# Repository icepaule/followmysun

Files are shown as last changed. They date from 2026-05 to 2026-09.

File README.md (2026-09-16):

# FollowMySun

> Astronomisch geführte Sonnenstand-Nachführung für ein einzelnes PV-Modul auf einem Gartenhaus-Dach. Basierend auf ESP8266 (ESP12F-Relay-X4), MPU-6050-Beschleunigungssensor und einem 12 V Linear-Aktuator – mit MQTT-Anbindung an Home Assistant inkl. Sturm-Notfallmodus.

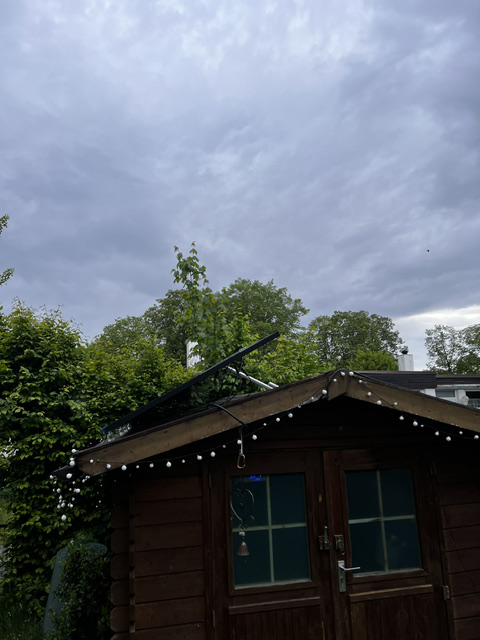
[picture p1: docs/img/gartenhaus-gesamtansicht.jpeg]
Gesamtansicht – Gartenhaus mit aufgestelltem PV-Panel


---

## Was macht das Ding?

Ein einzelnes PV-Modul auf dem 32°-Dach eines Gartenhauses wird durch einen 12 V Linear-Aktuator zwischen 32° (flach auf dem Dach) und ca. 59° (Aktuator voll ausgefahren) verstellt. Ein MicroPython-Programm auf einem ESP12F berechnet aus Datum, Uhrzeit und Standort den optimalen Panel-Winkel zur Sonne, misst per MPU-6050-Beschleunigungssensor den aktuellen Ist-Winkel und steuert über zwei Relais die Polarität am Aktuator.

Alle Werte werden per MQTT an einen Broker geschickt – damit baut sich in Home Assistant ein Live-Dashboard. Über ein Command-Topic (`cmnd/solar/EMERGENCY = on`) lässt sich das Panel bei Unwetterwarnung sofort flach auf das Dach fahren.

## Features

- **Astronomische Sonnenstand-Berechnung** für jeden Tag des Jahres und jede Tageszeit
- **MPU-6050-Regelung** mit asymmetrischer Hysterese (Start ab 2° Abweichung, Stopp ab 0,5° + Overshoot-Erkennung)
- **MQTT** mit JSON-Vollpayload + einzelnen Topics für Home-Assistant-Sensoren
- **Notfallmodus** über MQTT (`cmnd/solar/EMERGENCY`) – Panel sofort in Schutzposition
- **Hardware-Watchdog** (~3 s) gegen ESP-Hänger
- **WebREPL** zur Wartung übers WLAN (kein USB nötig nach Einbau)
- **Mini-Webserver** zur manuellen Steuerung im Browser
- **Kalibrierungs-Layer** mit Offset/Sign – Sensor-Achsenrichtung muss nicht physisch perfekt sitzen

## Hardware

| Bauteil | Funktion |
|---|---|
| **ESP12F-Relay-X4 v1.2** | ESP8266 + 4 Relais, davon 2 genutzt | 
| **MPU-6050 (GY-521)** | Beschleunigungssensor zur Winkelmessung |
| **Linear-Aktuator 12 V** mit Endschaltern | Verstellt das Panel-Gestell |
| **DC/DC-Stepdown-Wandler** | 12 V → 5 V Versorgung des ESP |
| **CAT5-Kabel ~2,5 m** | Verlängert I2C-Bus vom Controller zum Sensor am Panel |

### Steuerung im Gartenhaus

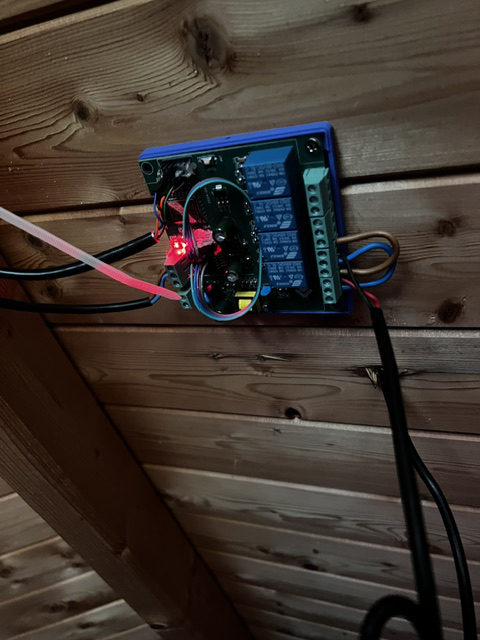
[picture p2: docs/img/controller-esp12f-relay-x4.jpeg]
ESP12F-Relay-X4 Controller im Gehäuse


Der Controller hängt geschützt unter der Dachschräge. Die zwei roten LEDs zeigen, welches Relais gerade aktiv ist.

### Stromversorgung

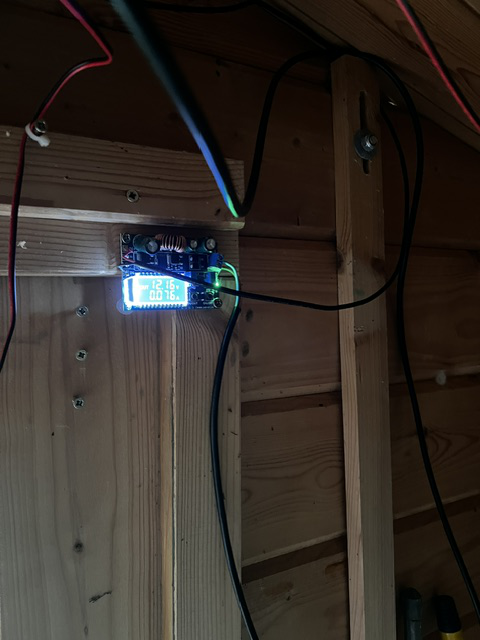
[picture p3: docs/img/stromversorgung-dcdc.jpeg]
DC/DC-Stepdown-Wandler 12V→5V


Ein einstellbarer Stepdown-Wandler erzeugt die 5 V für den ESP aus der 12 V Aktuator-Versorgung – ein Netzteil reicht für alles.

### MPU-Sensor am Panel

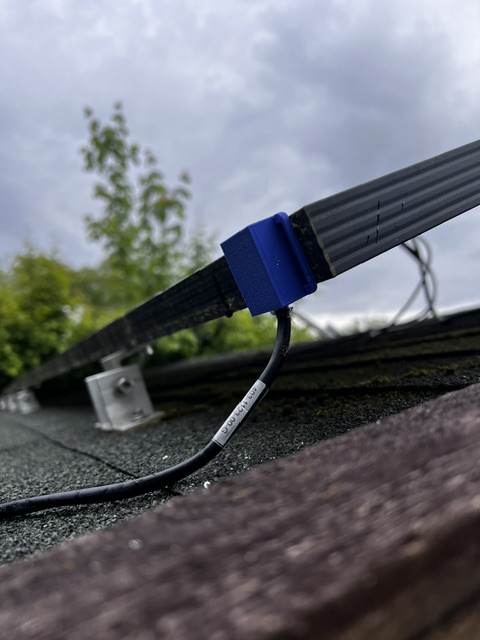
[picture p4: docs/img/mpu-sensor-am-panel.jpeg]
MPU-6050 am Panel-Rahmen


Der MPU-6050 sitzt in einem 3D-gedruckten Gehäuse direkt am PV-Rahmen und misst die Neigung gegen die Schwerkraft. Verkabelt mit CAT5 zum Controller.

## Schnellstart

1. **Hardware nach Pinbelegung verdrahten** (siehe [docs/hardware.md](docs/hardware.md))
2. **MicroPython auf ESP12F flashen** ([docs/installation.md](docs/installation.md))
3. **`src/env.example.py` → `env.py` kopieren** und Werte einfüllen (WLAN, MQTT, Sensor-Achsen)
4. **Code als `.mpy` kompilieren** (sonst MemoryError beim Parsen):
   ```bash
   python -m mpy_cross solar_main.py
   ```
5. **Dateien hochladen** (USB oder WebREPL): `boot.py`, `main.py`, `env.py`, `mpu6050.mpy`, `solar_main.mpy`
6. **Strom an** – fertig. Webseite unter `http://<esp-ip>/`, MQTT-Topics unter `tele/solar/...`

Detaillierte Anleitung: **[docs/installation.md](docs/installation.md)**

> **Migration auf ESP32 mit externer Antenne:** Wenn ihr das Setup an einem
> WLAN-schwachen Standort betreibt (z. B. Gartenhaus / Schuppen), gibt es eine
> ausführliche Umbau-Doku vom ESP12F-Relay-X4 auf den **Olimex ESP32-EVB-EA Rev.L**
> mit IPEX-Externantenne: **[docs/hardware-migration-esp32-evb.md](docs/hardware-migration-esp32-evb.md)** —
> inkl. Mermaid-Diagrammen für IST- und SOLL-Verkabelung sowie dem korrekten
> 12 V-Split über einen Mini-360-Buck (das neue Board ist strikt 5 V!).

### 3D-Druck-Gehäuse für den Olimex-Controller

Olimex ESP32-EVB-EA Rev.L Gehäuse v0.3

Für die Überkopfmontage des neuen Controllers **im Schuppen unter dem Dach** gibt es jetzt ein eigenes parametrisches Gehäuse in **v0.3**. Es bietet Zugang zu den sechs Aktuator-Schraubklemmen, Micro-USB, PWR1, UEXT/Dupont, externer WLAN-Antenne und RST1; der nicht benötigte CAN-Anschluss bleibt geschlossen.

- **[Gehäuse-Dokumentation](docs/housing-esp32-evb.md)** – Maße, Anschlussöffnungen, Explosionsansicht, Druckhinweise und Fit-Test
- **[OpenSCAD-Quelle + Build-Script](hardware/enclosure/olimex-esp32-evb-ea-v0.3/)** – erzeugt Base, Lid, Reset-Button, Fit-Test und ZIP reproduzierbar

## MQTT-Topics für Home Assistant

| Topic | Richtung | Beispiel | Beschreibung |
|---|---|---|---|
| `tele/solar/SENSOR` | ESP→ | JSON | Vollpayload mit allen Werten |
| `tele/solar/SENSOR/PanelAngle` | ESP→ | `35.4` | Aktueller Panel-Winkel (kalibriert) |
| `tele/solar/SENSOR/TargetAngle` | ESP→ | `42.1` | Soll-Winkel |
| `tele/solar/SENSOR/SunAngle` | ESP→ | `45.0` | Berechneter optimaler Winkel |
| `tele/solar/SENSOR/MotionText` | ESP→ | `Hoch` | `Stopp` / `Hoch` / `Runter` |
| `tele/solar/SENSOR/MinAngle` | ESP→ | `32.0` | Mechanisches Untermass |
| `tele/solar/SENSOR/MaxAngle` | ESP→ | `58.7` | Mechanisches Obermass |
| `tele/solar/SENSOR/Emergency` | ESP→ | `false` | Notfall-Status |
| `cmnd/solar/EMERGENCY` | →ESP | `on` / `off` | Notfall an/aus (retained!) |

Vollständig: **[docs/mqtt.md](docs/mqtt.md)** · NodeRED-Sturm-Automatik: **[docs/nodered-stormwatch.md](docs/nodered-stormwatch.md)**

## Notfall-Modus für Sturmwarnung

Aus Node-RED bei Unwetterwarnung:

```javascript
msg.topic = 'cmnd/solar/EMERGENCY';
msg.payload = 'on';
msg.retain = true;   // wichtig: ueberlebt ESP-Reboot
return msg;
```

Der ESP fährt das Panel sofort auf `MIN_ANGLE` (Dachneigung, flach) und ignoriert Auto-Modus + manuelle Web-Befehle. Bei `off` wechselt er zurück in den Astro-Modus.

## Repo-Struktur

```text
followmysun/
├── README.md
├── src/                       # Tracker-Firmware
├── docs/                      # Detail-Dokumentation
│   ├── hardware.md
│   ├── installation.md
│   ├── mqtt.md
│   ├── calibration.md
│   ├── tracker-debugging.md
│   ├── hardware-migration-esp32-evb.md
│   ├── housing-esp32-evb.md   # 3D-Druck-Gehäuse Olimex v0.3
│   └── img/
├── hardware/
│   └── enclosure/
│       └── olimex-esp32-evb-ea-v0.3/  # SCAD, Build, Rev-L-Koordinaten, QA
└── _config.yml
```

## Tech-Stack

- **MicroPython 1.28** auf ESP8266 (ESP12F)
- **mpy-cross** für Bytecode-Kompilierung (sonst RAM-Limit)
- **paho-mqtt / mosquitto** als Broker
- **MPU-6050** mit `atan2`-basierter Roll-Berechnung
- **SoftI2C @ 100 kHz** (wegen 2,5 m CAT5-Strecke)

Details siehe [docs/software.md](docs/software.md).

## Lessons Learned

Drei Sachen, die mich am meisten Zeit gekostet haben:

1. **`mqtt.ping()` darf nicht in jeder Loop-Iteration aufgerufen werden** – sonst stempelt der Broker dich als misbehaving und schmeißt dich mit `ECONNRESET` raus. Throttling auf 1×/30 s.
2. **ESP8266 WLAN braucht aktiven Outbound-Traffic**, sonst lernen Router/Switches die MAC nicht zuverlässig zurück – ein UDP-Keepalive pro Sekunde an die Gateway-IP löst's.
3. **`solar_main.py` ist mit 33 KB zu groß zum Parsen** auf dem ESP8266 (Heap ~35 KB). Lösung: vorher mit `mpy-cross` zu `.mpy` (10 KB) kompilieren.

## Lizenz

MIT – siehe [LICENSE](LICENSE).

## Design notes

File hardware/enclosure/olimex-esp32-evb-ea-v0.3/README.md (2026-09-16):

# Olimex ESP32-EVB-EA Rev. L – Schuppendach-Gehäuse v0.3

Parametrisches 3D-Druck-Gehäuse für den **Olimex ESP32-EVB-EA Rev. L** des FollowMySun-Controllers. Es ist für die Montage **innerhalb des Schuppens, über Kopf unter dem Dach** ausgelegt.

## v0.3

- Zugang zu **CON1 + CON2**: zwei 3-polige DG306-5.0-Schraubklemmen / insgesamt sechs Aktuator-Anschlüsse.
- Gemeinsame seitliche Kabeleinführung für die sechs Klemmen: **33,1 × 13,5 mm**.
- Zwei untere Schraubendreher-Servicefenster: je **13 × 14 mm**.
- **Micro-USB / USB-UART1**: **13 × 8,5 mm**.
- **WLAN**: Ø **10,0 mm** durchgehend.
- **PWR1**: **11 × 11 mm**.
- **UEXT/Dupont**: **16 × 7 mm**.
- **RST1** über separaten gedruckten Plunger.
- **Kein CAN-Ausschnitt**.

## Abmessungen

| Merkmal | Maß |
|---|---:|
| Gehäuse ohne Laschen | 94 × 92 × 31 mm |
| Wandstärke | 2,6 mm |
| PCB-Standoff | 4,0 mm |
| WLAN | Ø 10,0 mm |
| PWR1 | 11 × 11 mm |
| UEXT/Dupont | 16 × 7 mm |
| Micro-USB | 13 × 8,5 mm |
| CON1+CON2 Seitenöffnung | 33,1 × 13,5 mm |
| Servicefenster Klemmen | 2 × 13 × 14 mm |
| RST1 Wandbohrung | Ø 4,2 mm |
| Dach-Montagebohrungen | Ø 4,5 mm |

## Dateien

- `olimex_esp32_evb_ea_roof_housing_v0.3.scad` – komplettes parametrisches Modell.
- `build.sh` – rendert Base, Lid, RST-Button und Fit-Test als STL und erzeugt ein ZIP.
- `SOURCE_POSITIONS.md` – verwendete Rev.-L-Koordinaten.
- `MESH_QA.json` – Prüfergebnis der bereits erzeugten Referenz-STLs.

Die gerenderten Referenz-STLs sind wegen ihrer Größe nicht doppelt im Git-Tree abgelegt. Sie lassen sich mit `build.sh` aus der versionierten SCAD-Quelle reproduzieren.

## Bauen

Voraussetzungen: OpenSCAD CLI, `zip`, `sha256sum`.

```bash
cd hardware/enclosure/olimex-esp32-evb-ea-v0.3
chmod +x build.sh
./build.sh
```

Die Ergebnisse liegen danach unter `dist/`.

## Druck

Für den dauerhaften Einbau im Schuppen: **PETG oder ASA**. PLA eignet sich vor allem für den Fit-Test. Startwerte: 0,20 mm Layer, 4 Perimeter, 25–35 % Infill, 5 Top-/Bottom-Layer.

Vor dem großen Druck zuerst `fit_test_v0.3.stl` erzeugen und WLAN-, PWR-, Micro-USB- und Klemmenmaße am realen Aufbau prüfen.

Ausführliche Projektdokumentation: [`docs/housing-esp32-evb.md`](../../../docs/housing-esp32-evb.md).

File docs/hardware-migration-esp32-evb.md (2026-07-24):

---
title: Hardware-Migration ESP12F-Relay-X4 → Olimex ESP32-EVB-EA
---

# Hardware-Migration: ESP12F-Relay-X4 v1.2 → Olimex ESP32-EVB-EA Rev.L

Diese Doku beschreibt den Umbau des Solar-Tracker-Controllers vom ESP8266-basierten
**ESP12F-Relay-X4 v1.2** auf den ESP32-basierten **Olimex ESP32-EVB-EA Rev.L** mit
externer WLAN-Antenne. Ziel: mehr RAM, robusteres WLAN am schlechten Empfangsort
(Schuppen), OTA-Fähigkeit.

> → Alle vier Schaltbilder kompakt auf einer Seite: [Wiring-Übersicht ESP32-EVB](wiring-esp32-evb.html)

> **TL;DR** — Ihr könnt das alte Board 1:1 tauschen, müsst aber die **12 V-Zuleitung
> umkonzepieren**: das neue Board ist strikt 5 V. Nötig sind zusätzlich ein
> Mini-360 Step-Down und eine WAGO-T-Verzweigung.

## Warum tauschen

| Aspekt | ESP12F-Relay-X4 (alt) | Olimex ESP32-EVB-EA (neu) |
|---|---|---|
| MCU | ESP8266 @ 80/160 MHz | ESP32 dual-core @ 240 MHz |
| RAM | ~36 KB | 520 KB |
| Flash | 4 MB | 4 MB |
| WLAN-Antenne | PCB (auf ESP-12F) | externe IPEX + Stab-Antenne |
| Firmware-Form | `.mpy` (RAM-Druck) | `.py` direkt |
| OTA möglich | nein | ja |
| Crash-Profil | gelegentliche Heap-Crashes | nur noch Software-Bugs realistisch |

## Big Picture: alle Anschlüsse im Vergleich

| Aspekt | ALT – ESP12F-Relay-X4 v1.2 | NEU – Olimex ESP32-EVB-EA |
|---|---|---|
| Board-Stromversorgung | 12 V direkt an VIN-Klemme (Board hat eigenen Buck 12→5→3.3 V) | **Nur 5 V zulässig!** → Mini-360 Buck extern, dann DC-Jack 5.5×2.1 mm (Mitte +) |
| Aktuator-Versorgung | 12 V+ auf K1-COM, 12 V− auf K2-COM (vom Board-Vin abgezweigt) | 12 V+ auf REL1-COM, 12 V− auf REL2-COM (per WAGO parallel zur 5-V-Erzeugung) |
| Relais-Steuerung | GPIO16 (K1 = Runter), GPIO14 (K2 = Hoch) | GPIO32 (REL1 = Runter), GPIO33 (REL2 = Hoch) |
| I²C SDA | GPIO4 (D2) | GPIO13 = UEXT Pin 6 (Pull-up onboard) |
| I²C SCL | GPIO5 (D1) | GPIO16 = UEXT Pin 5 (Pull-up onboard) |
| MPU-6050 Versorgung | 3V3 + GND vom Board | 3V3 + GND aus UEXT Pin 1 / Pin 2 |
| Trenn-Bauteil dazwischen | keins nötig | **Mini-360 Step-Down** + **WAGO 221 T-Verzweigung** |

## Diagramm 1 — IST-Zustand ESP12F-Relay-X4

IST-Zustand ESP12F-Relay-X4

Der Boardregler zieht die 12 V selbst herunter, Relais K1/K2 schalten die
Aktuator-Adern in Polaritätsumkehr.

## Diagramm 2a — SOLL-Zustand Power-Pfad

SOLL Power-Pfad

Die 12 V-Zuleitung wird an einer WAGO 221 T-Verzweigung aufgeteilt:

- **Zweig A (Logik)**: 12 V → Mini-360 → getrimmt auf exakt 5.0 V → DC-Hohlstecker 5.5 × 2.1 mm (Mitte +) → Olimex DC-Jack → onboard TPS62A02 → 5 V / 3.3 V Rails.
- **Zweig B (Last)**: 12 V+ direkt an REL1-COM, 12 V− direkt an REL2-COM.

Gemeinsame Masse ist automatisch, weil beide Zweige aus derselben 12 V-Quelle kommen.

## Diagramm 2b — SOLL-Zustand Signal-/Last-Pfad

SOLL Signal- und Relais-Pfad

Olimex steuert die zwei Onboard-Relais REL1/REL2 (GPIO32/33), die Aktuator-Adern
hängen in Polarity-Reverse-Verdrahtung an NO/NC. MPU-6050 hängt komplett am
UEXT-Stecker (Pin 1/2/5/6).

## Diagramm 3 — Klemmen-Detail

Klemmen-Detail SOLL

Farbcode: rot = 12 V+, blau = 12 V−, gelb = 5 V, grün = Aktuator-Last.

## Stromversorgung Olimex — Warum kein 12 V direkt

Der onboard Buck-Regler des Olimex ESP32-EVB-EA ist ein **TPS62A02** mit
**Vin 2.5–5.5 V typ., abs. Max 6.5 V**. Alles darüber killt den Regler sofort.

Referenzen (offizielle Olimex-Doku):

- [ESP32-EVB Rev.L KiCad-Schaltplan (PDF)](https://github.com/OLIMEX/ESP32-EVB/blob/master/HARDWARE/REV-L/ESP32-EVB_Rev_L.pdf)
- [ESP32-EVB User Manual (PDF)](https://github.com/OLIMEX/ESP32-EVB/blob/master/DOCS/ESP32-EVB-user-manual.pdf)
- [TI TPS62A02 Datenblatt](https://www.ti.com/product/TPS62A02A)

### Was am Olimex **nicht** geht

- 12 V an DC-Jack — zerstört den TPS62A02.
- 12 V an EXT/UEXT Pin 1 — das ist der 5-V-Rail-Ausgang, kein Input.
- 12 V an die Schraubklemmen des Boards — die sind Relais-Kontakte (COM/NO/NC), keine Versorgung.
- PoE über RJ45 — der EVB hat keine PoE-PHY (das ist die separate `ESP32-POE`-Variante).

### Was geht

1. **DC-Jack 5.5 × 2.1 mm, Mitte +**, gespeist aus Mini-360-VOUT — cleanster Weg, Reverse-Polarity-Diode auf dem Board schützt.
2. **Micro-USB**, gespeist aus 5-V-USB-Netzteil oder Mini-360 + aufgetrenntes USB-Kabel — genauso sicher, mechanisch etwas fragiler.
3. **LiPo-Header** JST-PH 2 mm (`BAT1`) — nur wenn Batterie geplant.

### Auslegung Mini-360

| | |
|---|---|
| Last (Olimex + CH340 + MPU + 2 Relais-Spulen) | ~450 mA @ 5 V ≈ 2.25 W |
| Mini-360 max dauerhaft | 1.8 A → >4-fache Reserve |
| Wärme im geschlossenen Gehäuse | Handwarm; bei Bedenken: LM2596 mit Kühlkörper oder Traco TSR-1-2450 |

## Verkabelung Motor (Polarity-Reverse-Pattern)

Die zwei externen Relais des alten Aufbaus entfallen komplett — die Motor- und
Power-Adern gehen direkt in die Schraubklemmen der zwei Onboard-Relais des Olimex.

| Funktion | ALT – ESP12F-Relay-X4 | NEU – Olimex ESP32-EVB-EA |
|---|---|---|
| Motor „Runter" Steuerung | GPIO16 → K1-Spule (Board-intern) | GPIO32 (REL1) – onboard |
| Motor „Hoch" Steuerung | GPIO14 → K2-Spule (Board-intern) | GPIO33 (REL2) – onboard |
| Aktuator + | K1-NO | **REL1-NO + REL2-NC** |
| Aktuator − | K2-NO | **REL2-NO + REL1-NC** |
| 12 V + | K1-COM | **REL1-COM** |
| 12 V − | K2-COM | **REL2-COM** |

**Wenn Motorrichtung verkehrt**: entweder `PIN_RELAY1` / `PIN_RELAY2` in `env.py`
tauschen ODER Aktuator-Adern mechanisch in den Klemmen kreuzen — nicht beides.

## Verkabelung MPU-6050 an UEXT

Alle vier Adern gehen in den 10-pol IDC-UEXT-Stecker. Kein Löten nötig.

| MPU-6050 | ALT – ESP12F-Relay-X4 | NEU – Olimex UEXT (10-pol IDC) |
|---|---|---|
| VCC | 3V3 Stiftleiste | **UEXT Pin 1 (+3.3 V)** |
| GND | GND Stiftleiste | **UEXT Pin 2 (GND)** |
| SCL | GPIO5 (D1) | **UEXT Pin 5 → GPIO16** (Pull-up onboard) |
| SDA | GPIO4 (D2) | **UEXT Pin 6 → GPIO13** (Pull-up onboard) |
| AD0 | an GND (Adr. 0x68) | an GND (unverändert) |

UEXT-Pinout (Sicht von oben aufs Board, Pin 1 markiert):

```
   1 +3.3V    2 GND
   3 TXD      4 RXD
   5 SCL      6 SDA    ←── MPU-6050 hier
   7 MISO     8 MOSI
   9 SCK     10 SS
```

## Zusätzliche Bauteile

| Menge | Bauteil | Zweck | Bezug (Beispiel) |
|---|---|---|---|
| 1 | **Olimex ESP32-EVB-EA Rev.L** | neuer Controller | [olimex.com](https://www.olimex.com/Products/IoT/ESP32/ESP32-EVB/) ~20 € |
| 1 | **Mini-360** DC-DC-Buck (alternativ LM2596 mit Kühlkörper) | 12 V → 5.0 V für Olimex-Logik | Amazon 8er-Set ~8 € |
| 1 | **DC-Hohlstecker 5.5 × 2.1 mm, Mitte +**, zum Anlöten | Mini-360 → Olimex DC-Jack | Amazon / Reichelt |
| 2 | **WAGO 221** (3-Leiter) | T-Verzweigung 12 V+ und 12 V− | Baumarkt |
| 1 | **UEXT-IDC-Ribbon-Kabel 10-pol** (2×5, 2.54 mm, IDC-Buchse mit Codierung) | MPU-6050 an UEXT | Amazon (siehe unten) |
| — | 0.75 mm² / 1.5 mm² Kabel, Aderendhülsen | Verlängerung zu WAGO | Vorrat |
| — | Multimeter | Mini-360 auf 5.00 V trimmen | Vorrat |

## Werkbank-Checkliste

- [ ] Strom AUS am alten Solar-Tracker-Standort (12 V-Netzteil ausstecken)
- [ ] Antenne am Olimex: IPEX-Pigtail eingerastet + SMA-Stab aufgeschraubt (**VOR** Power-On!)
- [ ] Mini-360 auf der Werkbank auf **5.00 V trimmen** (Multimeter am Ausgang, ohne Olimex angeschlossen)
- [ ] WAGO 221 A (12 V+): 12 V+ vom Netzteil rein, 2 Leiter raus (zu Mini-360-VIN+ und zu REL1-COM)
- [ ] WAGO 221 B (12 V−): 12 V− vom Netzteil rein, 2 Leiter raus (zu Mini-360-VIN− und zu REL2-COM)
- [ ] DC-Hohlstecker: Mini-360-VOUT+ auf Innen-Pin, VOUT− auf Ring, in Olimex-DC-Jack
- [ ] Aktuator-Adern beim Erstboot noch ABGEKLEMMT lassen (GPIO32/33 wackeln kurz beim Boot)
- [ ] MPU-6050 4-adrig am UEXT-Stecker (Pin 1/2/5/6)
- [ ] 12 V-Netzteil einstecken → Olimex-LEDs an, Mini-360-LED an
- [ ] Nachmessen: DC-Jack-Eingang am Olimex zeigt 5.0 V (± 0.1)
- [ ] Aktuator-Adern in REL1/REL2-Klemmen gemäß Polarity-Reverse-Schema (Diagramm 3)
- [ ] Firmware-Deployment: `env.py`, `boot.py`, `main.py`, `mpu6050.py`, `solar_main.py` via `mpremote`
- [ ] Reset + MQTT-Test
- [ ] Motorrichtung OK? Falls nicht: PIN_RELAY1/2 in env.py tauschen ODER Aktuator-Adern kreuzen
- [ ] WLAN-RSSI prüfen — Erwartung ≥ −65 dBm mit externer Antenne

## Sicherheits-Reminder

- **Nie 12 V direkt** in irgendeinen Anschluss des Olimex.
- **Nie ohne Antenne** einschalten, wenn WLAN-Betrieb geplant ist (HF-Reflexion → Modul-Schaden).
- Mini-360-Poti **nie unter Last** verstellen (Overshoot möglich).
- Motor-Adern beim Erstboot **abklemmen** (Boot-Klick der Relais).
- **Keine 230 V** auf die Olimex-Relais — der Aufbau ist mechanisch nicht dafür isoliert.

## Firmware-Änderungen

Zur ESP8266→ESP32-Portierung sind minimale Code-Anpassungen nötig:

- **Firmware-Flash-Offset**: `0x1000` (statt `0x0` wie ESP8266).
- **PowerSave**: `sta.config(pm=sta.PM_NONE)` in `boot.py` (statt `esp.sleep_type(esp.SLEEP_NONE)`).
- **Compat-Shim** in `solar_main.py` für `esp.sleep_type()` (no-op auf ESP32).
- Kein `.mpy`-Compile mehr nötig; `solar_main.py` läuft direkt.
- **`init()`-Reihenfolge umgedreht**: WLAN zuerst → MQTT → MPU (optional) → HTTP → WDT. Damit bleibt der Remote-Zugang auch dann garantiert, wenn der MPU-6050 (noch) nicht am UEXT hängt. `sensor = None` sperrt automatisch jegliche Motorbewegung (Sicherheit), Web + MQTT laufen normal weiter und melden `MpuOk:false` inkl. Fehlercode.
- **Watchdog-Timeout: 30 s** (statt fest 3 s wie beim ESP8266) — genug Reserve, damit ein langsamer HTTP-Request keinen falschen Reset auslöst.

Siehe [software.md](software.md) für die generellen Firmware-Details.

## Eingebautes WebGUI + REST-API

Ausreichend RAM auf dem ESP32 (~80 kB frei im Betrieb) macht es möglich, den früher gestrichenen Mini-Webserver wieder mitlaufen zu lassen — nonblocking im Main-Loop, ohne Threads. Aufrufbar direkt unter `http://<esp-ip>/`:

- **Dashboard** (Auto-Refresh alle 4 s): Panel-Winkel, Ziel-Winkel, Sonnen-Winkel, Motorstatus, Emergency/Manual-Flags, WLAN-RSSI, Heap, Uptime, MPU-Status, ggf. LastError.
- **Motor manuell**: Buttons **Hoch / Runter / Auto**.
- **Notfall**: **EMERGENCY ON / OFF** (Panel sofort flach) + **Recalc** (Sonne neu berechnen).
- **Kalibrierung / Grenzen**: Feld für `SetAngle <grad>` (kalibriert den MPU-Offset live und persistiert ihn nach `/calib.json`) + Feld für `MIN_ANGLE` (0–70°).

Alle Aktionen laufen intern über dieselben Helper wie die MQTT-Commands (`action_set_emergency`, `action_manual`, `action_setangle`, `action_recalc`, `action_set_minangle`) — die REST-Endpoints sind ein reiner Alias-Pfad neben dem MQTT-Bus.

### REST-Endpoints

| Methode | Pfad | Payload (form-encoded) | Antwort |
|---|---|---|---|
| `GET` | `/` | — | HTML-Dashboard |
| `GET` | `/api/state` | — | JSON-Snapshot (identisches Schema wie MQTT-Topic `tele/solar/SENSOR`) |
| `POST` | `/api/manual` | `v=up\|down\|auto` | text/plain, z.B. `Manual: Up` |
| `POST` | `/api/emergency` | `v=on\|off` | `Emergency on` / `Emergency off` |
| `POST` | `/api/recalc` | — | `recalc: sun=X target=Y` |
| `POST` | `/api/setangle` | `v=<grad>` | `calib: offset=Z, panel=<grad>` |
| `POST` | `/api/minangle` | `v=<grad>` | `MIN_ANGLE=<grad>` |

Beispiel mit `curl`:

```bash
curl http://10.10.12.55/api/state | jq
curl -X POST -d "v=on"  http://10.10.12.55/api/emergency
curl -X POST -d "v=45"  http://10.10.12.55/api/setangle
```

## Reverse-Proxy für Zugriff aus getrenntem VLAN

Wenn der Tracker in einem isolierten IoT-VLAN sitzt (z.B. Firewall-Regel „nur MQTT + Internet raus"), erreicht euer Client-Netz den Web-Port `:80` nicht direkt. Ein kleiner nginx-Container auf einem Host im Zwischennetz (z.B. der HA-Server) proxied durch:

```nginx
# /etc/nginx/conf.d/pv-tracker.conf
server {
  listen 8055;
  location / {
    proxy_pass http://10.10.12.55;
    proxy_http_version 1.1;
    proxy_set_header Host $host;
    proxy_read_timeout 8s;
  }
}
```

als Docker One-Liner:

```bash
docker run -d --name pv-tracker-proxy --restart unless-stopped \
  -p 8055:80 \
  -v /opt/pv-tracker-proxy/nginx.conf:/etc/nginx/nginx.conf:ro \
  nginx:alpine
```

Danach ist das Dashboard unter `http://<HA-server-IP>:8055/` aus dem regulären LAN erreichbar und kann per **Home Assistant `panel_iframe`** direkt eingebettet werden.

## IP-Reservierung für den Olimex

Der Olimex meldet sich mit einer eigenen MAC-Adresse (bei uns `38:18:2b:e5:70:8c`), also bekommt er eine **neue DHCP-Lease** und nicht die alte ESP12F-IP. Zwei Möglichkeiten:

1. **Neue Reservation** — im DHCP-Server / UniFi-Controller die neue MAC auf die gewünschte feste IP pinnen und die alte ESP12F-Reservation komplett löschen.
2. **Aktuelle DHCP-Lease pinnen** — falls die neue IP OK ist, einfach `use_fixedip=true` mit dem aktuellen Wert setzen, damit sie nicht wandert.

Alle bestehenden HA-/Node-RED-Integrationen bleiben unberührt, weil MQTT-Client-ID (`esp_solar`) und alle Topics gleich bleiben — der IP-Wechsel betrifft nur das WebGUI-Bookmark und den Reverse-Proxy.

## Live gefunden beim Werkbank-Bootstrap (2026-07-20)

- **Serial-Port nicht erraten, sondern per USB-IDs identifizieren:** `/dev/ttyUSB0`/`/dev/ttyUSB1` sind keine stabile Zuordnung, wenn mehrere USB-Seriell-Geräte am selben Host hängen (hier: ein Zigbee-Dongle auf `ttyUSB0`, das Olimex-Board erst auf `ttyUSB1`). Vorher gegenprüfen: `udevadm info -q property -n /dev/ttyUSBx` — das Olimex-Board meldet sich als CH340-Serial-Konverter (`ID_VENDOR_ID=1a86`, `ID_MODEL_ID=7523`).
- **`mpremote exec`/WebREPL-Diagnosebefehle unterbrechen ein bereits laufendes `main.py`** (wirkt wie Ctrl-C auf die REPL) — für reines Mitlesen ohne Eingriff stattdessen den seriellen Port passiv auslesen (z.B. `pyserial` ohne zu senden), sonst kommt der Tracker nie über die WLAN-Verbindung hinaus, weil jeder Diagnose-Check ihn erneut unterbricht.
- **`02-setup-wifi-webrepl.sh` verbindet WLAN nur einmalig innerhalb der eigenen Skript-Session** (schreibt lediglich `webrepl_cfg.py`) — ohne bereits deploytes `boot.py`/`main.py` verbindet sich das Board nach einem Reset noch nicht automatisch. Fürs allererste Deployment daher `mpremote connect port:<port> fs cp <datei> :<datei>` (seriell, kein WLAN nötig) statt `03-deploy.sh` (WebREPL, braucht bereits WLAN).
- ~~**`init()` bricht kontrolliert vor dem WLAN-Connect ab, wenn kein MPU-6050 am I2C-Bus antwortet** (`ENODEV`) — Absicht (kein blindes Verfahren des Aktuators ohne Winkelsensor), aber auf der reinen Werkbank ohne UEXT-Sensor bleibt WLAN/MQTT dadurch aus. Für einen Bootstrap-Test ohne Sensor ist das also kein Fehler, sondern erwartetes Verhalten.~~ **Behoben 2026-07-24**: `init()` startet jetzt zuerst WLAN + MQTT + WebGUI, MPU ist optional. Bei fehlendem Sensor bleibt lediglich der Motor gesperrt (`sensor is None` verhindert jede Relais-Aktion), Remote-Zugang und Diagnose laufen aber weiter — genau so, wie man es für den Bootstrap braucht.
- **Speicher-Bestätigung:** frischer Boot zeigt ~151 KB freien Heap (ESP32) gegenüber ~29 KB beim ESP8266 zum Vergleich — bestätigt, dass `solar_main.py` auf dieser Generation wie vorgesehen direkt als Rohquelltext läuft, kein `.mpy`-Precompile nötig.
- ⚠️ **Parallelbetrieb-Falle:** Solange der alte ESP8266-Tracker noch produktiv im Feld läuft, darf ein Werkbank-Test des neuen ESP32 **nicht** dieselbe `MQTT_CLIENT_ID` ("esp_solar") nutzen — der Broker trennt sonst die ältere (echte) Verbindung. Zusätzlich sind `tele/solar/LWT`, `tele/solar/PING_ECHO` und `tele/solar/BOOT` in `solar_main.py` **hart codiert** (nicht über `env.py`-Variablen geführt wie `MQTT_TOPIC_SENSOR`/`_DEBUG`/`_CMD`) — für einen isolierten Werkbank-Test müssen diese drei Topic-Strings temporär mit umbenannt werden (z.B. `tele/solar_bench/...`), sonst überschreibt der Testaufbau den retained LWT-Status des echten Trackers in Home Assistant. TODO: diese drei Topics ebenfalls über `env.py` konfigurierbar machen, um das für künftige Parallel-Tests nicht mehr manuell patchen zu müssen.

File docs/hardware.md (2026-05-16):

---
title: Hardware-Aufbau
---

# Hardware-Aufbau

Komplette Stückliste, Pinbelegung und Verkabelung.

## Stückliste

| # | Bauteil | Bezugsquelle (Beispiel) | Preis ca. |
|---|---|---|---|
| 1 | **ESP12F-Relay-X4 v1.2** (ESP8266 + 4 SPDT-Relais) | AliExpress | ~10 € |
| 2 | **MPU-6050 GY-521** Beschleunigungssensor | AliExpress | ~2 € |
| 3 | **Linear-Aktuator 12 V** mit integrierten Endschaltern (Hub passend) | Amazon | 30–80 € |
| 4 | **DC/DC-Stepdown-Wandler** 12 V→5 V (z.B. MP1584) | AliExpress | ~3 € |
| 5 | **12 V Netzteil** (Strom ≥ Aktuator-Anlaufstrom, ~2 A) | – | 10–20 € |
| 6 | **CAT5-Kabel** (~2,5 m je nach Distanz Controller↔Sensor) | – | – |
| 7 | **PV-Modul** mit Schwenk-Gestell | – | – |
| 8 | 3D-gedrucktes Sensor-Gehäuse (optional, witterungsfest) | selbst | – |
| 9 | Aderendhülsen, Schraubklemmen, Lüsterklemmen | – | – |

## Pinbelegung ESP12F-Relay-X4

Das Board nutzt intern feste GPIO-Pins für seine Relais:

| Relais | GPIO | Code-Konstante | Funktion |
|---|---|---|---|
| K1 | GPIO 16 | `PIN_RELAY1` | **Motor Runter** (Aktuator einfahren) |
| K2 | GPIO 14 | `PIN_RELAY2` | **Motor Hoch** (Aktuator ausfahren) |
| K3 | GPIO 12 | – | (frei) |
| K4 | GPIO 13 | – | (frei) |

Freie GPIOs für I2C:

| Pin | GPIO | Code-Konstante | Funktion |
|---|---|---|---|
| D2 | GPIO 4 | `PIN_I2C_SDA` | I2C SDA (Daten) |
| D1 | GPIO 5 | `PIN_I2C_SCL` | I2C SCL (Takt) |

Steuerung im Gartenhaus

## Verkabelung Motor (Polaritätsumkehr-Schaltung)

Linear-Aktuator hat zwei Drähte – die Drehrichtung kommt aus der Polarität. Mit zwei SPDT-Relais wird die Polarität umgeschaltet. **NO/COM/NC sind die drei Anschlüsse pro Relais auf der Klemmleiste.**

```
+12V (gross) ────┬──────────┐
                 │          │
              K1.NO       K2.NO
                 │          │
              K1.COM     K2.COM
                 │          │
            Aktuator-A   Aktuator-B
                 │          │
              K1.NC      K2.NC
                 │          │
 GND (gross) ────┴──────────┘
```

| K1 | K2 | Draht A | Draht B | Aktuator |
|---|---|---|---|---|
| OFF | OFF | GND | GND | steht (beidseitig GND = Bremse) |
| **ON** | OFF | **+12 V** | GND | fährt eine Richtung |
| OFF | **ON** | GND | **+12 V** | fährt andere Richtung |

**Wenn nach erstem Test die Richtung verkehrt herum ist:** nicht im Code drehen, sondern Aktuator-Drähte A↔B tauschen. Der Code-Kommentar (`K1 = Runter, K2 = Hoch`) bleibt dann konsistent.

## Verkabelung MPU-6050

I2C-Bus, vier Drähte. Bei meinem Aufbau ~2,5 m **CAT5-Patchkabel** zwischen Controller im Gartenhaus und Sensor am Panel. Verwendete Aderbelegung (eigene Konvention – einmal festgelegt und durchgehalten):

| MPU-6050-Pin | ESP12F-Pin | CAT5-Ader |
|---|---|---|
| **VCC (3,3 V)** | 3V3 | **blau** |
| **GND** | GND | **grün** |
| **SDA** | D2 (GPIO 4) | **orange** |
| **SCL** | D1 (GPIO 5) | **braun** |

Die jeweils mit-verdrillte „weiß-…"-Ader der CAT5-Paare wird nicht benutzt oder als zweite GND-Ader genutzt. **Wichtig**: SDA und SCL nicht im gleichen verdrillten Paar zusammen – die hohen Pegelwechsel würden sich gegenseitig stören. Lieber Power-Paar (blau+weißblau für VCC/GND) und Daten-Paare getrennt.

> Bei längeren Strecken (>1 m) sollte I2C auf **100 kHz** statt 400 kHz laufen, sonst CRC-Fehler. Im Code per `machine.SoftI2C(..., freq=100000)` gesetzt.

> **MPU-Modul** mit 5 V VCC funktioniert auch, hat dann aber den onboard-LDO als Wärmequelle. 3,3 V direkt vom ESP-Board ist sauberer.

MPU-Sensor am Panel-Rahmen

## MPU-Orientierung am Panel

Der MPU misst Roll als `atan2(accel_y, accel_z)`. Damit positive Werte „Panel steiler" bedeuten, gilt folgende Konvention:

| MPU-Achse | muss zeigen nach… |
|---|---|
| **+Z** (aus Bauteilseite raus) | weg vom Panel (Bauteilseite ins Freie, Pin-Header-Seite ans Panel) |
| **X** | parallel zur Drehachse des Panels (entlang Pin-Header-Reihe) |
| **+Y** | zur Hochkante des Panels (wo das Panel beim Aufstellen hochgeht) |

**Wenn beim ersten Test der Wert verkehrtes Vorzeichen hat oder einen ~90°-Offset zeigt:** im Code über die Kalibrierungs-Parameter korrigieren statt am Sensor schrauben. Siehe [calibration.md](calibration.md).

## Stromversorgung

Ein einziges **12 V Netzteil** versorgt zwei Pfade:

```
                ┌──────────────────────────┐
12 V Netzteil ──┤  Aktuator (über Relais)  │
                └──────────────────────────┘
                ┌──────────────────────────┐
            └───┤  DC/DC Stepdown 12V→5V   │
                │        ↓                 │
                │     ESP-Board VIN        │
                └──────────────────────────┘
```

**12 V-Pfad:**
- Direkt auf die große grüne Klemmleiste am ESP12F-Relay-X4 (versorgt das Board)
- Zusätzlich per Drahtbrücken auf `K1.NO`+`K2.NO` (= +12 V für Aktuator)
- GND-Brücken auf `K1.NC`+`K2.NC` (= GND für Aktuator-Rückführung)

**5 V-Pfad** (für ESP-Logik):
- Stepdown-Wandler hat zwei Schraubklemmen Eingang (12 V IN, GND) und zwei Ausgang (5 V OUT, GND)
- Ausgang auf 5 V einstellen (Poti drehen, mit Multimeter messen, **bevor** der ESP angeschlossen wird)
- Dann 5 V an den ESP-Board-Vin-Pin (nicht 3V3 – der hat einen eigenen Onboard-LDO)

Der Stepdown sollte für mindestens 500 mA bei 5 V ausgelegt sein. ESP braucht meist 100–300 mA, Spitzenstrom beim WLAN-Senden bis 500 mA. Typen wie **MP1584** oder **LM2596** mit Display sind günstig und solide.

Stromversorgung 12V→5V

Auf dem Display sieht man im Betrieb `IN ≈ 12,46 V / OUT ≈ 5,16 V` – der Wandler hält die 5 V auch bei Aktuator-Anlauflasten stabil.

## Empfohlene Erweiterungen

- **Sicherung 2 A** in der 12 V-Leitung vor dem Aktuator (Brand-Schutz)
- **Optokoppler oder zusätzliche Trennung** zwischen ESP und Aktuator-Versorgung (Funkenflug bei Relais-Schalten)
- **Wasserdichtes Gehäuse** für den MPU am Panel (IP65)
- **Endschalter-Backup** im Code (auch wenn der Aktuator eigene Endschalter hat)

## Gesamtansicht

Gartenhaus mit aufgestelltem Panel

Der schwarze Aktuator-Arm ist gut zu sehen – er hebt das Panel über die First-Linie hinaus an, sodass es der Sonne nachgeführt wird.

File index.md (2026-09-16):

---
title: FollowMySun
layout: default
---

# FollowMySun

> **Astronomisch geführte Sonnenstand-Nachführung für ein einzelnes PV-Modul auf einem Gartenhaus-Dach.** Basierend auf ESP8266 (ESP12F-Relay-X4), MPU-6050-Beschleunigungssensor und einem 12 V Linear-Aktuator – mit MQTT-Anbindung an Home Assistant inkl. Sturm-Notfallmodus.

Gartenhaus mit aufgestelltem PV-Panel

---

## Inhalt

- [Was macht das System?](#was-macht-das-system)
- [Features](#features)
- [Hardware-Aufbau](docs/hardware.html)
- [Installation Schritt-für-Schritt](docs/installation.html)
- [MQTT-Integration für Home Assistant](docs/mqtt.html)
- [NodeRED-Sturmwarnung-Flow](docs/nodered-stormwatch.html)
- [Sensor-Kalibrierung](docs/calibration.html)
- [Software-Architektur](docs/software.html)
- [Tracker-Debugging und Quellbasis](docs/tracker-debugging.html) — aktuelle Laufzeit-Variante, Quellbasis und Debug-Checkliste
- [Hardware-Migration ESP12F → Olimex ESP32-EVB-EA](docs/hardware-migration-esp32-evb.html) — Umbau für WLAN-schwache Standorte, externe Antenne, korrekter 12 V-Split
- [3D-Druck-Gehäuse Olimex ESP32-EVB-EA](docs/housing-esp32-evb.html) — Überkopfmontage im Schuppen, sechs Aktuator-Klemmen, Micro-USB und OpenSCAD-Quelldateien
- [Wiring-Übersicht ESP32-EVB](docs/wiring-esp32-evb.html) — alle vier Schaltbilder auf einer Seite, als Werkbank-Referenz
- [Source-Code auf GitHub](https://github.com/icepaule/followmysun)

## Was macht das System?

Ein einzelnes PV-Modul auf dem 32°-Dach eines Gartenhauses wird durch einen 12 V Linear-Aktuator zwischen 32° (flach auf dem Dach) und ca. 59° (Aktuator voll ausgefahren) verstellt. Ein MicroPython-Programm auf einem ESP12F berechnet aus Datum, Uhrzeit und Standort den optimalen Panel-Winkel zur Sonne, misst per MPU-6050-Beschleunigungssensor den aktuellen Ist-Winkel und steuert über zwei Relais die Polarität am Aktuator.

Alle Werte werden per MQTT an einen Broker geschickt – damit baut sich in Home Assistant ein Live-Dashboard. Über ein Command-Topic (`cmnd/solar/EMERGENCY = on`) lässt sich das Panel bei Unwetterwarnung sofort flach auf das Dach fahren.

## Features

- **Astronomische Sonnenstand-Berechnung** für jeden Tag des Jahres und jede Tageszeit
- **MPU-6050-Regelung** mit asymmetrischer Hysterese (Start ab 2° Abweichung, Stopp ab 0,5° + Overshoot-Erkennung)
- **MQTT** mit JSON-Vollpayload + einzelnen Topics für Home-Assistant-Sensoren
- **Notfallmodus** über MQTT (`cmnd/solar/EMERGENCY`) – Panel sofort in Schutzposition
- **Hardware-Watchdog** (~3 s) gegen ESP-Hänger
- **WebREPL** zur Wartung übers WLAN (kein USB nötig nach Einbau)
- **Mini-Webserver** zur manuellen Steuerung im Browser
- **Kalibrierungs-Layer** mit Offset/Sign – Sensor-Achsenrichtung muss nicht physisch perfekt sitzen

## Hardware-Bilder

<table>
  <tr>
    <td style="vertical-align:top;padding:8px;">
      Controller
      <p style="margin-top:6px;"><b>Controller</b> – ESP12F-Relay-X4 im Gartenhaus-Inneren</p>
    </td>
    <td style="vertical-align:top;padding:8px;">
      Stromversorgung
      <p style="margin-top:6px;"><b>Stromversorgung</b> – 12 V → 5 V Stepdown-Wandler mit Display</p>
    </td>
  </tr>
  <tr>
    <td style="vertical-align:top;padding:8px;">
      MPU-Sensor
      <p style="margin-top:6px;"><b>MPU-6050</b> – im 3D-Druck-Gehäuse direkt am Panel-Rahmen</p>
    </td>
    <td style="vertical-align:top;padding:8px;">
      Gesamtansicht
      <p style="margin-top:6px;"><b>Gesamtansicht</b> – Panel über dem Dachfirst</p>
    </td>
  </tr>
</table>

## Neues Controller-Gehäuse für Olimex ESP32-EVB-EA

3D-Druck-Gehäuse für Olimex ESP32-EVB-EA Rev.L

Für die ESP32-Migration ist ein eigenes **parametrisches v0.3-Gehäuse** für die Überkopfmontage unter dem Schuppendach hinzugekommen. Zugänglich bleiben die sechs Aktuator-Schraubklemmen, Micro-USB, PWR1, UEXT/Dupont, WLAN-Antenne und RST1; CAN wird nicht benötigt und bleibt geschlossen.

→ [Gehäuse, Explosionsansicht, Maße und Druckanleitung](docs/housing-esp32-evb.html)

## Schnellstart

1. Hardware nach Pinbelegung verdrahten ([hardware.html](docs/hardware.html))
2. MicroPython auf ESP12F flashen ([installation.html](docs/installation.html))
3. `src/env.example.py` nach `env.py` kopieren und Werte einfüllen
4. Code zu `.mpy` kompilieren: `python -m mpy_cross solar_main.py`
5. Dateien hochladen (USB oder WebREPL)
6. Strom an – fertig

## Tech-Stack

MicroPython 1.28 · ESP8266 (ESP12F) · MPU-6050 GY-521 · 12 V Linear-Aktuator · mosquitto/paho-mqtt · Home Assistant · Node-RED

## Lizenz

MIT — siehe [LICENSE auf GitHub](https://github.com/icepaule/followmysun/blob/main/LICENSE).

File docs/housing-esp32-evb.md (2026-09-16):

---
title: 3D-Druck-Gehäuse für Olimex ESP32-EVB-EA Rev.L
---

# 3D-Druck-Gehäuse für Olimex ESP32-EVB-EA Rev.L

Für die neue ESP32-Version des FollowMySun-Controllers gibt es ein eigenes parametrisches Gehäuse. Es ist speziell für die **Überkopfmontage innerhalb des Schuppens unter dem Dach** konstruiert: Die Grundplatte bleibt am Dach verschraubt, während der Deckel zur Wartung von unten abgenommen werden kann.

Gesamtansicht des Olimex-Gehäuses

Aktueller Stand: **v0.3**. Die Geometrie basiert auf den Board-Koordinaten des offiziellen OLIMEX-KiCad-Layouts für **ESP32-EVB Rev.L**.

## Konstruktionsprinzip

- Vier außenliegende Laschen befestigen die Grundplatte an der Unterseite des Schuppendachs.
- Das Olimex-Board sitzt auf drei 4-mm-Standoffs an den originalen Rev-L-Montagepunkten.
- Die Bauteilseite zeigt nach unten in das Gehäuse.
- Der Deckel wird von unten aufgesetzt und mit vier M3-Schrauben befestigt.
- Der Reset-Taster `RST1` ist über einen separaten gedruckten Plunger erreichbar.
- Belüftungsschlitze liegen auf der nach unten gerichteten Seite und sind damit gegen den meisten herabfallenden Staub geschützt.

## Anschlüsse

| Anschluss | Gehäuseöffnung | Zweck |
|---|---:|---|
| WLAN / externe Antenne | Ø **10,0 mm** | Durchführung für den externen Antennenanschluss |
| PWR1 | **11 × 11 mm** | 5-V-Hohlstecker / Kabelkörper |
| UEXT1 | **16 × 7 mm** | einzelne Dupont-Leitungen zum MPU-6050 |
| USB-UART1 / Micro-USB | **13 × 8,5 mm** | lokale Konsole, Flashen und Wartung |
| CON1 + CON2 | **33,1 × 13,5 mm** seitlich | sechs Relais-/Aktuator-Klemmen |
| Klemmschrauben | **2 × 13 × 14 mm** unten | Schraubendreherzugang zu beiden 3-poligen Klemmenblöcken |
| RST1 | Ø **4,2 mm** | gedruckter Reset-Plunger |
| CAN | **keine Öffnung** | für FollowMySun nicht benötigt |

Die beiden DG306-5.0-Klemmen `CON1` und `CON2` sitzen direkt an der Platinenkante. Die v0.3 verwendet deshalb eine gemeinsame seitliche Öffnung für alle sechs Anschlusspositionen und zusätzlich zwei getrennte Wartungsfenster im Deckel. Dadurch lassen sich die Aktuatorleitungen auch bei montierter Grundplatte von unten lösen oder nachziehen.

## Explosionsansicht

Explosionsansicht des Olimex-Gehäuses

Das Board bleibt bei Wartungsarbeiten auf der dachseitigen Grundplatte. Deckel und Reset-Plunger können separat demontiert werden.

## Abmessungen

- Gehäuse ohne Befestigungslaschen: **94 × 92 × 31 mm**
- Wandstärke: **2,6 mm**
- PCB-Standoff: **4,0 mm**
- Dach-Montagebohrungen: **Ø 4,5 mm**
- RST-Plunger-Schaft: **Ø 3,55 mm**, Länge **11,0 mm**

Die Passmaße sind am Anfang der SCAD-Datei als Parameter definiert und können ohne Neukonstruktion geändert werden.

## Quelldateien und STL-Build

Die parametrische Quelle liegt hier:

[`hardware/enclosure/olimex-esp32-evb-ea-v0.3/`](../hardware/enclosure/olimex-esp32-evb-ea-v0.3/)

Wichtige Dateien:

- [`olimex_esp32_evb_ea_roof_housing_v0.3.scad`](../hardware/enclosure/olimex-esp32-evb-ea-v0.3/olimex_esp32_evb_ea_roof_housing_v0.3.scad) – komplettes Modell
- [`SOURCE_POSITIONS.md`](../hardware/enclosure/olimex-esp32-evb-ea-v0.3/SOURCE_POSITIONS.md) – verwendete Rev-L-Koordinaten
- [`MESH_QA.json`](../hardware/enclosure/olimex-esp32-evb-ea-v0.3/MESH_QA.json) – Prüfung der Referenz-STLs
- [`build.sh`](../hardware/enclosure/olimex-esp32-evb-ea-v0.3/build.sh) – erzeugt Base, Lid, Reset-Button, Fit-Test und das ZIP-Paket

Mit installiertem OpenSCAD:

```bash
cd hardware/enclosure/olimex-esp32-evb-ea-v0.3
chmod +x build.sh
./build.sh
```

Danach enthält `dist/`:

```text
base_v0.3.stl
lid_v0.3.stl
rst_button_v0.3.stl
fit_test_v0.3.stl
olimex_esp32_evb_ea_roof_housing_v0.3.zip
MANIFEST_SHA256.txt
```

## Vor dem großen Druck: Fit-Test

Zuerst nur `fit_test_v0.3.stl` drucken. Damit lassen sich die kritischen realen Passungen mit sehr wenig Material prüfen:

1. WLAN-Anschluss durch Ø10 mm testen.
2. PWR-Stecker gegen 11 × 11 mm prüfen.
3. Micro-USB-Kabel samt Kunststoffkörper durch 13 × 8,5 mm prüfen.
4. UEXT/Dupont-Kabelbündel gegen 16 × 7 mm prüfen.
5. Schraubendreherzugang für die Aktuator-Klemmen prüfen.

Erst danach Base und Lid drucken. FDM-Bohrungen fallen abhängig von Drucker und Material oft geringfügig kleiner aus; deshalb ist der Testcoupon Bestandteil des Modells.

## Druckempfehlung

Für den endgültigen Einsatz unter dem Schuppendach **PETG oder ASA** verwenden. PLA ist für Passproben geeignet, kann sich aber bei sommerlicher Hitze unter dem Dach verformen.

Startwerte:

- 0,20 mm Layerhöhe
- 4 Perimeter
- 25–35 % Infill
- 5 Top-/Bottom-Layer
- Base flach, Posts nach oben
- Lid ist im STL bereits mit der geschlossenen Außenseite zum Druckbett orientiert
- RST-Button mit der Kappe auf dem Druckbett
- normalerweise keine Supports erforderlich

## Mesh-Prüfung

Die Referenz-STLs der v0.3 wurden nach dem Rendern geprüft. Base, Lid, RST-Button und Fit-Test sind jeweils **wasserdichte Einzelmeshes** (`watertight = true`, jeweils eine Komponente). Details stehen in [`MESH_QA.json`](../hardware/enclosure/olimex-esp32-evb-ea-v0.3/MESH_QA.json).

## Zusammenhang mit dem Controller-Umbau

Das Gehäuse gehört zur Migration des Trackers auf den Olimex-Controller:

- [Hardware-Migration ESP12F → Olimex ESP32-EVB-EA](hardware-migration-esp32-evb.html)
- [Wiring-Übersicht ESP32-EVB](wiring-esp32-evb.html)

Die sechs zugänglichen Schraubanschlüsse sind dabei die beiden Onboard-Relais `CON1`/`CON2`, über die 12-V-Versorgung und Linear-Aktuator im Polarity-Reverse-Schema angeschlossen werden.

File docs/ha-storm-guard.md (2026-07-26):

---
title: HA Storm Guard (lokale Wind-Automatik)
---

# HA Storm Guard – lokale Wind-Sturm-Automatik

**Status: live deployed und verifiziert (Stand 26.07.2026)**

Ziel: Bei anhaltend hohem Wind an der lokalen Wetterstation wird das PV-Panel automatisch in die Schutzposition (`MIN_ANGLE`, ~32°, flach auf dem Dach) gefahren. Bei anhaltend ruhigem Wind kehrt es zurück in den Auto-Modus. **Komplett in Home Assistant** – der ESP-Controller bleibt firmware-mäßig unverändert.

## Warum ein zweiter Sturmschutz?

Es gibt bereits [einen DWD-basierten Sturmschutz per NodeRED](nodered-stormwatch.md), der offizielle Unwetterwarnungen des Deutschen Wetterdienstes auswertet. Der greift aber nur bei behördlich ausgegebenen Warnungen. Ein lokaler Windstoss von 40 km/h aus einer Gewitterzelle ohne Warnung würde ihn nicht triggern.

Der Storm Guard hier ergänzt das um eine **lokale, sensor-basierte Auslösung**:

| Trigger | Quelle | Latenz | Deckt |
|---|---|---|---|
| NodeRED-Sturmwatch | DWD Warnstufe + NINA | Minuten | Angekündigte Unwetter |
| **HA Storm Guard** | Lokale Wetterstation `sensor.tasmota_iceweather_windspeed` | ~1 Min | Lokale Windstöße |

Beide setzen dasselbe Ziel: `cmnd/solar/EMERGENCY on` → Panel flach.

## Architektur

```mermaid
flowchart LR
    A[IceWeatherstation<br/>tele/iceweatherstation/SENSOR<br/>WindSpeed m/s] -->|MQTT| B[HA MQTT-Sensor<br/>tasmota_iceweather_windspeed]
    B --> C[Template Sensor<br/>sensor.pv_wind_km_h<br/>= raw × 3.6]
    B --> D{Template-Trigger<br/>Wind > Schwelle<br/>für Dauer}
    D -->|yes| E[HA Automation<br/>Storm Guard Activate]
    E --> F[REST Command<br/>POST http://10.10.0.100:8055/api/emergency<br/>v=on]
    F -->|HTTP| G[nginx pv-tracker-proxy]
    G -->|proxy| H[Olimex 10.10.12.55<br/>action_set_emergency=true<br/>target=MIN_ANGLE]
    style D fill:#fff3cd
    style E fill:#d4edda
    style H fill:#cfe2ff
```

**Wichtige Design-Entscheidung – HTTP statt MQTT-Command:** Der `cmnd/solar/EMERGENCY`-MQTT-Sub wird auf dem Olimex zeitweise unzuverlässig (nach MQTT-Reconnects gehen Subscriptions manchmal verloren). Das direkt über HTTP an den `/api/emergency`-Endpoint zu schicken ist zuverlässiger und braucht keine dauerhafte Subscription am Board.

## Olimex WebGUI (unverändert)

Der Tracker selbst zeigt seinen Live-Zustand weiterhin unter `http://<nuc-ha-ip>:8055/`:

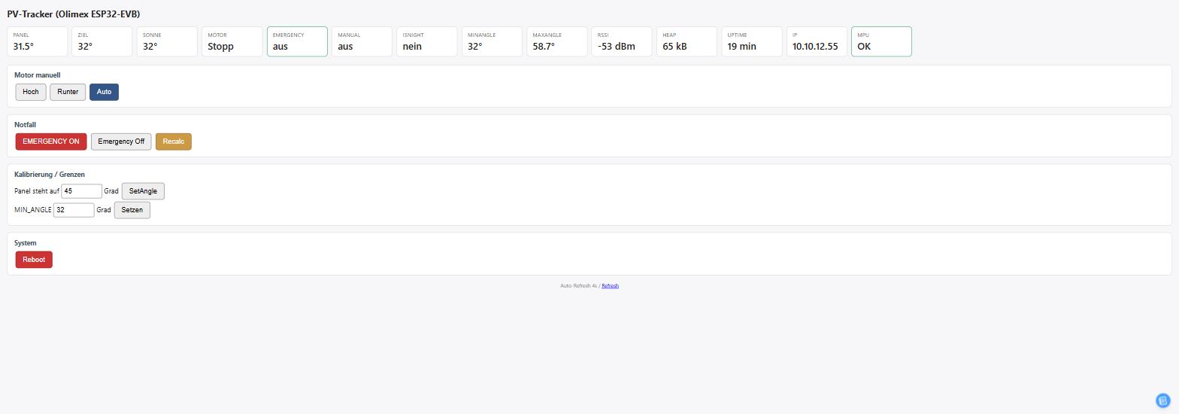
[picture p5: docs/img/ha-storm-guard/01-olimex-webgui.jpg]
Olimex WebGUI – Live Dashboard mit Panel/Ziel/Motor/Emergency-Status


Wenn Storm Guard triggert → HA POST an `/api/emergency` → `Emergency` wechselt auf `an`, Target auf MinAngle. Der Reboot-Button rechts unten stammt aus der `/api/reboot`-Ergänzung (commit 65ecf99).

## HA Helpers-Übersicht

Alle 6 Storm-Guard-Helper unter **Settings → Devices & Services → Helpers**:

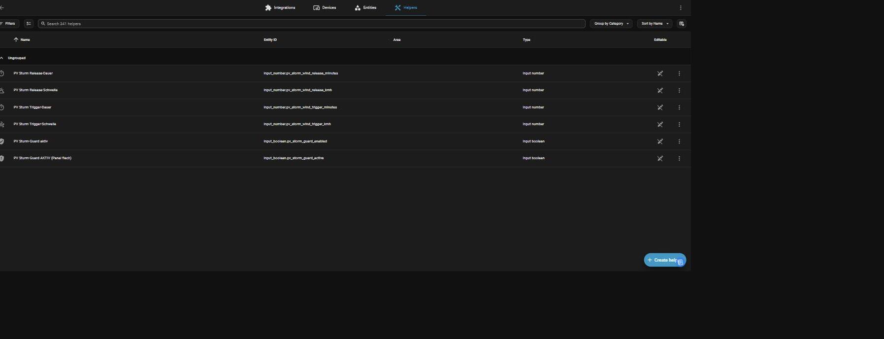
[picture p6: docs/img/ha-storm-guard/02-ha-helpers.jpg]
HA Helpers gefiltert auf pv_storm – 4 Input-Numbers + 2 Input-Booleans


## HA Automations-Übersicht

Die 3 Storm-Guard-Automations unter **Settings → Automations**:

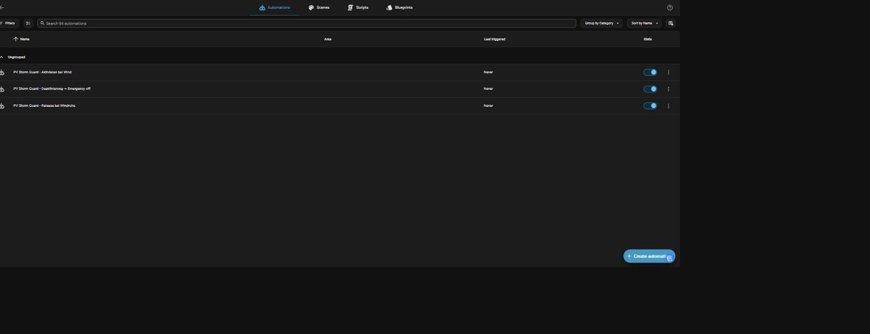
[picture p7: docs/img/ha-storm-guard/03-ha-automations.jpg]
HA Automations gefiltert auf 'storm guard' – Aktivieren, Deaktivierung, Release, alle ON


„Last triggered: Never" bedeutet: der aktuelle Wind (~2 km/h zum Screenshot-Zeitpunkt) hat noch nie den Trigger-Schwellwert erreicht — Storm Guard ist scharf aber schlafend.

## Konfigurierbare Parameter

Alle in HA-UI editierbar unter **Einstellungen → Geräte & Dienste → Helfer**:

| Helper | Default | Bedeutung |
|---|---|---|
| `input_boolean.pv_storm_guard_enabled` | ON | Master-Schalter – aus = keine Automatik |
| `input_boolean.pv_storm_guard_active` | OFF (auto) | Anzeige: gerade ein Sturm-Guard aktiv? |
| `input_number.pv_storm_wind_trigger_kmh` | 30 | Wind muss darüber gehen |
| `input_number.pv_storm_wind_trigger_minutes` | 1 | ...und mindestens so lange |
| `input_number.pv_storm_wind_release_kmh` | 10 | Wind muss darunter gehen |
| `input_number.pv_storm_wind_release_minutes` | 10 | ...und mindestens so lange |
| `sensor.pv_wind_km_h` | (auto) | Live-Wind in km/h (m/s × 3.6) |

## Zustands-Diagramm

```mermaid
stateDiagram-v2
    [*] --> Normal
    Normal --> Storm: Wind > TriggerKmh<br/>für TriggerMin
    Storm --> Normal: Wind < ReleaseKmh<br/>für ReleaseMin
    Storm --> Normal: Guard deaktiviert
    note right of Storm
        Emergency=ON
        target=MIN_ANGLE
        Panel flach
    end note
    note right of Normal
        Emergency=OFF
        target=optimaler Winkel
        Sonnennachführung
    end note
```

## Home Assistant Package

Das komplette Paket liegt unter `packages/pv_storm_guard.yaml` (relativ zum HA-Config-Verzeichnis, aktiviert über `packages: !include_dir_named packages/`).

```yaml
# =============================================================================
# PV STORM GUARD - HA-seitige Wind-Sturm-Automatik fuer den Solar-Tracker
# =============================================================================
input_number:
  pv_storm_wind_trigger_kmh:
    name: "PV Sturm Trigger-Schwelle"
    min: 5
    max: 100
    step: 1
    initial: 30
    unit_of_measurement: "km/h"
    icon: mdi:weather-windy

  pv_storm_wind_release_kmh:
    name: "PV Sturm Release-Schwelle"
    min: 0
    max: 50
    step: 1
    initial: 10
    unit_of_measurement: "km/h"
    icon: mdi:weather-partly-cloudy

  pv_storm_wind_trigger_minutes:
    name: "PV Sturm Trigger-Dauer"
    min: 1
    max: 30
    step: 1
    initial: 1
    unit_of_measurement: "min"

  pv_storm_wind_release_minutes:
    name: "PV Sturm Release-Dauer"
    min: 1
    max: 60
    step: 1
    initial: 10
    unit_of_measurement: "min"

input_boolean:
  pv_storm_guard_enabled:
    name: "PV Sturm-Guard aktiv"
    icon: mdi:shield-check
  pv_storm_guard_active:
    name: "PV Sturm-Guard AKTIV (Panel flach)"
    icon: mdi:shield-alert

template:
  - sensor:
      - name: "PV Wind km/h"
        unique_id: pv_wind_kmh
        state: >-
          {{ (states('sensor.tasmota_iceweather_windspeed') | float(0) * 3.6) | round(1) }}
        unit_of_measurement: "km/h"
        icon: mdi:weather-windy

rest_command:
  solar_emergency_on:
    url: "http://10.10.0.100:8055/api/emergency"
    method: POST
    content_type: "application/x-www-form-urlencoded"
    payload: "v=on"
    timeout: 8

  solar_emergency_off:
    url: "http://10.10.0.100:8055/api/emergency"
    method: POST
    content_type: "application/x-www-form-urlencoded"
    payload: "v=off"
    timeout: 8

automation:
  - id: pv_storm_guard_activate
    alias: "PV Storm Guard - Aktivieren bei Wind"
    mode: single
    trigger:
      - platform: template
        value_template: >-
          {{ (states('sensor.tasmota_iceweather_windspeed') | float(0))
             > (states('input_number.pv_storm_wind_trigger_kmh') | float(30) / 3.6) }}
        for:
          minutes: "{{ states('input_number.pv_storm_wind_trigger_minutes') | int(1) }}"
    condition:
      - condition: state
        entity_id: input_boolean.pv_storm_guard_enabled
        state: "on"
      - condition: state
        entity_id: input_boolean.pv_storm_guard_active
        state: "off"
    action:
      - service: rest_command.solar_emergency_on
      - service: input_boolean.turn_on
        target:
          entity_id: input_boolean.pv_storm_guard_active
      - service: logbook.log
        data:
          name: "PV Storm Guard"
          message: >-
            AKTIVIERT - Wind {{ states('sensor.pv_wind_km_h') }} km/h ueber
            {{ states('input_number.pv_storm_wind_trigger_kmh') }} km/h fuer
            {{ states('input_number.pv_storm_wind_trigger_minutes') }} min

  - id: pv_storm_guard_release
    alias: "PV Storm Guard - Release bei Windruhe"
    mode: single
    trigger:
      - platform: template
        value_template: >-
          {{ (states('sensor.tasmota_iceweather_windspeed') | float(999))
             < (states('input_number.pv_storm_wind_release_kmh') | float(10) / 3.6) }}
        for:
          minutes: "{{ states('input_number.pv_storm_wind_release_minutes') | int(10) }}"
    condition:
      - condition: state
        entity_id: input_boolean.pv_storm_guard_active
        state: "on"
    action:
      - service: rest_command.solar_emergency_off
      - service: input_boolean.turn_off
        target:
          entity_id: input_boolean.pv_storm_guard_active

  - id: pv_storm_guard_disabled_cleanup
    alias: "PV Storm Guard - Deaktivierung -> Emergency off"
    mode: single
    trigger:
      - platform: state
        entity_id: input_boolean.pv_storm_guard_enabled
        to: "off"
    condition:
      - condition: state
        entity_id: input_boolean.pv_storm_guard_active
        state: "on"
    action:
      - service: rest_command.solar_emergency_off
      - service: input_boolean.turn_off
        target:
          entity_id: input_boolean.pv_storm_guard_active
```

## Test-Kommandos

Kann jederzeit manuell getriggert werden ohne auf Wind zu warten:

```bash
# HA-Token setzen
TOKEN="..."

# Emergency ON per REST-Command
curl -X POST -H "Authorization: Bearer $TOKEN" \
  http://10.10.10.100:8123/api/services/rest_command/solar_emergency_on -d '{}'

# Status prüfen am Olimex direkt
curl -s http://10.10.0.100:8055/api/state | jq '.SENSOR.Emergency'
# → true

# Zurückstellen
curl -X POST -H "Authorization: Bearer $TOKEN" \
  http://10.10.10.100:8123/api/services/rest_command/solar_emergency_off -d '{}'
```

## Debugging

**Storm Guard reagiert nicht auf Wind?**

1. `sensor.tasmota_iceweather_windspeed` — hat der Werte? (`< 30 s` alt)
2. `input_boolean.pv_storm_guard_enabled` — ist auf ON?
3. Manueller Test: REST-Command wie oben triggern — kommt Emergency auf true?
4. HA-Log filtern nach `pv_storm_guard`
5. `sensor.pv_wind_km_h` — zeigt einen sinnvollen Wert?

**Panel geht nicht flach obwohl Emergency=true?**

1. `sensor.solartracker_target_angle` — sollte auf MIN_ANGLE stehen
2. Aktuator-Sicherung/Verkabelung prüfen
3. MPU-Status prüfen: `curl http://10.10.0.100:8055/api/state | jq .SENSOR.MpuOk`

## Bezug zu anderen Komponenten

- **[NodeRED Storm Watch](nodered-stormwatch.md)** – DWD-basiert, ergänzt Storm Guard um behördliche Warnungen
- **[Hardware Migration ESP32-EVB](hardware-migration-esp32-evb.md)** – Firmware-Basis auf Olimex
- **[MQTT-Topics](mqtt.md)** – bestehende cmnd/tele-Struktur (Storm Guard nutzt HTTP-API statt Command-Topic)

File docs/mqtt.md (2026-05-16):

---
title: MQTT-Integration
---

# MQTT-Topics

Alle Topics, ihre Bedeutung und Beispiele für Home-Assistant + Node-RED.

## Telemetrie (ESP → Broker)

Wird alle 30 s gesendet, zusätzlich sofort bei Motor-Statuswechsel.

### Vollpayload (JSON)

**Topic:** `tele/solar/SENSOR`

```json
{
  "Time": "16.05.2026 18:35:18",
  "SENSOR": {
    "PanelAngle": 35.4,
    "PanelAngleRaw": 122.7,
    "TargetAngle": 42.1,
    "SunAngle": 45.0,
    "MinAngle": 32.0,
    "MaxAngle": 58.7,
    "SensorOffset": 87.3,
    "SensorSign": 1,
    "Tolerance": 2.0,
    "Motion": 1,
    "MotionText": "Hoch",
    "Manual": false,
    "Emergency": false,
    "IsNight": false
  },
  "SYSTEM": {
    "Uptime": 3612,
    "HeapFree": 14400,
    "WiFiRSSI": -70,
    "NTPSyncCount": 1,
    "BootTime": "16.05.2026 17:35:06",
    "LastError": null
  },
  "STATUS": {
    "Online": true,
    "IP": "192.168.178.92"
  }
}
```

### Einzel-Topics (für HA-Sensoren)

| Topic | Beispiel | Typ | Beschreibung |
|---|---|---|---|
| `tele/solar/SENSOR/PanelAngle` | `35.4` | float | Aktueller Winkel zur Horizontalen (kalibriert) |
| `tele/solar/SENSOR/PanelAngleRaw` | `122.7` | float | Roh-MPU-Wert (Debug/Kalibrierung) |
| `tele/solar/SENSOR/TargetAngle` | `42.1` | float | Soll-Winkel |
| `tele/solar/SENSOR/SunAngle` | `45.0` | float | Berechneter optimaler Winkel (vor Clamping) |
| `tele/solar/SENSOR/MinAngle` | `32.0` | float | Mechanisches Untermass |
| `tele/solar/SENSOR/MaxAngle` | `58.7` | float | Mechanisches Obermass |
| `tele/solar/SENSOR/Motion` | `1` | int | 0 = Stopp, 1 = Hoch, 2 = Runter |
| `tele/solar/SENSOR/MotionText` | `Hoch` | string | Lesbar |
| `tele/solar/SENSOR/Manual` | `false` | bool | True wenn Manual-Override aktiv |
| `tele/solar/SENSOR/Emergency` | `false` | bool | True im Notfallmodus |
| `tele/solar/SENSOR/IsNight` | `true` | bool | True nach Sonnenuntergang |

### Status-Topics

| Topic | Bedeutung |
|---|---|
| `stat/esp_solar/STATUS` | `online` / `offline` (retained, last-will) |
| `stat/solar/DEBUG` | JSON mit Motor-Events und Fehlern |

## Commands (Broker → ESP)

### Notfall-Modus

**Topic:** `cmnd/solar/EMERGENCY`
**Payload:** `on`, `off`, `1`, `0`, `true`, `false`, `yes`

```bash
mosquitto_pub -h <broker> -u user -P pw \
  -t cmnd/solar/EMERGENCY -m on -r
```

Das `-r` (retain) ist **wichtig** – sonst geht der Notfall-Zustand beim nächsten ESP-Reboot verloren.

Bei `EMERGENCY=on`:
- `target = MIN_ANGLE` (z.B. 32°)
- Manual-Override wird gelöscht
- Astro-Berechnung und IsNight werden ignoriert
- Echo zurück auf `tele/solar/SENSOR/Emergency = true`
- Webseite zeigt roten NOTFALL-Banner

## Home Assistant Konfiguration

In `configuration.yaml`:

```yaml
mqtt:
  sensor:
    - name: "Solar Panel-Winkel"
      state_topic: "tele/solar/SENSOR/PanelAngle"
      unit_of_measurement: "°"
      icon: "mdi:angle-acute"
    - name: "Solar Ziel-Winkel"
      state_topic: "tele/solar/SENSOR/TargetAngle"
      unit_of_measurement: "°"
    - name: "Solar Motor-Status"
      state_topic: "tele/solar/SENSOR/MotionText"
      icon: "mdi:cog"

  binary_sensor:
    - name: "Solar Notfall"
      state_topic: "tele/solar/SENSOR/Emergency"
      payload_on: "true"
      payload_off: "false"
      device_class: safety

  switch:
    - name: "Solar Notfall-Modus"
      command_topic: "cmnd/solar/EMERGENCY"
      state_topic: "tele/solar/SENSOR/Emergency"
      payload_on: "on"
      payload_off: "off"
      state_on: "true"
      state_off: "false"
      retain: true
```

## Node-RED bei Unwetterwarnung

```javascript
// Beispiel-Flow: bei aktiver Unwetterwarnung Panel sichern
if (msg.payload === true || msg.payload === "active") {
    return {
        topic: "cmnd/solar/EMERGENCY",
        payload: "on",
        retain: true
    };
} else {
    return {
        topic: "cmnd/solar/EMERGENCY",
        payload: "off",
        retain: true
    };
}
```

## Topic-Übersicht zum Subscribe

```bash
# Alles anschauen
mosquitto_sub -h <broker> -u user -P pw -t 'tele/solar/#' -t 'stat/solar/#' -v

# Nur State-Werte
mosquitto_sub -h <broker> -u user -P pw -t 'tele/solar/SENSOR/+' -v
```

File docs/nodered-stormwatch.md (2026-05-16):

---
title: NodeRED Sturmwarnung-Flow
---

# Sturmwarnung-Automatik mit Home Assistant + NodeRED

**Status: live deployed und verifiziert (Stand 16.05.2026)**

Ziel: Bei aktiver Unwetterwarnung wird das PV-Panel automatisch in die sichere Position (flach auf dem Dach, `MIN_ANGLE = 32°`) gefahren – ohne dass jemand zuhause sein muss. Bei Entwarnung kehrt das System in den Auto-Modus zurück.

## Architektur

```
[DWD Warnstufe]   [NINA Schwere]   [Manual-Override]
       │                │                  │
       └────────────────┴──────────────────┘
                        │
                        ↓
       [HA Aggregat-Sensor:
        binary_sensor.pv_emergency_trigger]
                        │   (state-change)
                        ↓
       [NodeRED Flow "Solar PV-Emergency"]
              │           ↑
              │           │ (Echo-Monitor)
              ↓           │
        [MQTT cmnd/solar/EMERGENCY]
              │           │
              │           │
              ↓           │
        [ESP12F]──────────┘
        Panel auf MIN_ANGLE       (Echo: tele/solar/SENSOR/Emergency)
```

## Komponente 1: HA-Aggregat-Sensor

`binary_sensor.pv_emergency_trigger` wird `true` wenn **mindestens eine** der drei Bedingungen zutrifft:

| Bedingung | Quelle |
|---|---|
| `DWD current_warning_level >= 2` für Ottobrunn | DWD Weather Warnings Integration |
| NINA-Schwere = "Schwer" oder "Extrem" | NINA-Integration |
| `input_boolean.pv_emergency_force = on` | Manueller Override-Switch im HA |

Der Sensor hat zusätzlich ein Attribut `reason`, das im Klartext zeigt, warum er getriggert hat – z.B. `"DWD Level 3 + NINA Schwer"`. Praktisch fürs Dashboard und für die Notification.

### Beispiel: template binary_sensor

```yaml
template:
  - binary_sensor:
      - name: "PV Emergency Trigger"
        unique_id: pv_emergency_trigger
        state: >
          {{ states('sensor.dwd_current_warning_level_ottobrunn') | int(0) >= 2
             or states('sensor.nina_warning_severity') in ['Schwer','Extrem']
             or is_state('input_boolean.pv_emergency_force','on') }}
        attributes:
          reason: >
            {% set parts = [] %}
            {% set lvl = states('sensor.dwd_current_warning_level_ottobrunn') | int(0) %}
            {% if lvl >= 2 %}{% set parts = parts + ['DWD Level ' ~ lvl] %}{% endif %}
            {% set sev = states('sensor.nina_warning_severity') %}
            {% if sev in ['Schwer','Extrem'] %}{% set parts = parts + ['NINA ' ~ sev] %}{% endif %}
            {% if is_state('input_boolean.pv_emergency_force','on') %}{% set parts = parts + ['Manual-Override'] %}{% endif %}
            {{ parts | join(' + ') if parts else 'kein Trigger' }}
```

## Komponente 2: NodeRED-Flow „Solar PV-Emergency"

Eigener Tab mit drei Gruppen:

### Gruppe „Trigger"
- **Node `server-state-changed`** – lauscht auf `binary_sensor.pv_emergency_trigger`
- **Switch-Node** – verzweigt: state == `on` → Pfad ON, state == `off` → Pfad OFF

### Gruppe „Publish"
- **Function-Node ON** baut MQTT-Payload:
  ```javascript
  return {
      topic:   'cmnd/solar/EMERGENCY',
      payload: 'on',
      retain:  true,
      qos:     1
  };
  ```
- **Function-Node OFF** analog mit `payload: 'off'`
- **MQTT-out** über Broker-Konfiguration `mqtt_nuc`

### Gruppe „Echo-Monitor"
- **Server-state-changed** auf `binary_sensor.solartracker_emergency_echo`
- Loggt / visualisiert die Quittung des ESP zurück nach HA (ca. 2 s Reaktionszeit)

### Bonus: Startup-Inject
- **Inject-Node** auf `flow start` mit `delay: 10s`
- Republisht den aktuellen `pv_emergency_trigger`-State, damit der Zustand auch nach NodeRED-Restarts neu rausgeht (sonst würde der Broker den retained-State weiter halten, was OK ist – aber so ist NodeRED auch konsistent)

## Komponente 3: HA-Echo-Sensor

```yaml
mqtt:
  binary_sensor:
    - name: "Solartracker Emergency Echo"
      unique_id: solartracker_emergency_echo
      state_topic: "tele/solar/SENSOR/Emergency"
      payload_on: "true"
      payload_off: "false"
      device_class: safety
      icon: mdi:shield-home
```

Das ist die **Quittung vom ESP**: erst wenn der Echo-Sensor auf `on` umspringt, hat der Aktuator wirklich die Anweisung empfangen. Latenz im Live-Test: ~2 s.

## Komponente 4: Dashboard-Card

Eine Subview im HA-Dashboard zeigt:

- **Trigger** (`binary_sensor.pv_emergency_trigger`)
- **Grund** (Attribute `reason`)
- **Echo** vom ESP (`binary_sensor.solartracker_emergency_echo`)
- **Force-Switch** (`input_boolean.pv_emergency_force`)
- **DWD-Level** (`sensor.dwd_current_warning_level_ottobrunn`)
- **NINA-Status** (`sensor.nina_warning_severity`)

So sieht man auf einen Blick: ist es scharf, warum, und hat der ESP es quittiert.

## Live-Test (Stand 16.05.2026, 19:59)

| Schritt | Ergebnis |
|---|---|
| `input_boolean.pv_emergency_force` → on | `pv_emergency_trigger` springt auf on |
| NodeRED publisht `cmnd/solar/EMERGENCY = on retain` | gesendet |
| ESP empfängt → `stat/solar/DEBUG` *"Emergency ON"* | empfangen |
| ESP publisht `tele/solar/SENSOR/Emergency = true` | empfangen |
| HA-Echo (`solartracker_emergency_echo`) flippt auf on | **~2 s nach Trigger** |
| `pv_emergency_force` → off | umgekehrte Sequenz, sauber |

## Persistenz nach ESP-Reboot

Weil das MQTT-Command mit `retain=true` gesendet wird, hält der Broker es. Wenn das ESP rebootet (Stromausfall, WDT-Reset, Update), subscribed es beim Boot wieder auf `cmnd/solar/EMERGENCY` – und der Broker liefert sofort den retained Wert nach. Falls dieser `on` ist, ist das ESP **unmittelbar nach dem Boot wieder im Notfallmodus**, ohne dass NodeRED etwas tun muss.

## Backups

Vor dem Deployment wurden gesichert:
- `flows.json.bak.pre-pv-emergency-20260516-195501`
- `energie_v2.yaml.bak.pre-solartracker-20260516-192320`

## Optional: Notifications

```yaml
automation:
  - alias: "PV-Notfall-Aktivierung melden"
    trigger:
      - platform: state
        entity_id: binary_sensor.solartracker_emergency_echo
        to: 'on'
    action:
      - service: notify.mobile_app
        data:
          title: "Solar-Panel im Notfallmodus"
          message: >
            Panel auf 32° flach. Grund:
            {{ state_attr('binary_sensor.pv_emergency_trigger','reason') }}
```

Damit weißt du sofort wenn DWD/NINA das System scharfgeschaltet hat und du nicht zufällig im Garten warst.

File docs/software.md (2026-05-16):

---
title: Software-Architektur
---

# Software-Architektur

Für Leser, die den Code lesen und ändern wollen.

## Datei-Layout auf dem ESP

```
/boot.py            #  64 B  - MicroPython startet zuerst
/main.py            # 155 B  - laedt solar_main.mpy (Bytecode-Trick fuer ESP8266-RAM)
/env.py             # ~3 KB  - lokale Konfiguration (Secrets - nicht im Git)
/mpu6050.mpy        # ~1 KB  - kompilierter I2C-Treiber
/solar_main.mpy     # ~12 KB - kompilierter Hauptcode
```

`solar_main.py` als Quelle ist ~33 KB – wegen RAM-Limit (~35 KB Heap) muss er als `.mpy` (compiled bytecode) hochgeladen werden, sonst `MemoryError` beim Parsen.

## Boot-Sequenz

1. **boot.py** wird von MicroPython automatisch zuerst geladen
   - `esp.sleep_type(esp.SLEEP_NONE)` – Modem-Sleep aus (wird später nochmal nach `wlan.connect()` gesetzt)
   - `network.WLAN(AP_IF).active(False)` – AP-Interface aus
   - WebREPL starten (Port 8266)
2. **main.py** importiert `solar_main` (= führt es aus)
3. **solar_main** lädt `env.py`, initialisiert Hardware, WLAN, NTP, MQTT, Webserver, dann `loop()` für immer

## Hauptloop

```
while True:
    handle_web_request()        # nonblocking accept, 0.5s recv timeout
    mqtt_check_connection()     # ggf. reconnect, check_msg(), ping (1×/30s)

    if 24h vorbei: sync_time()  # NTP
    if 150ms vorbei: sensor.get_angle_roll() + kalibrieren
    if 10min vorbei: calculate_optimal_angle() + target setzen
    if 30s vorbei: mqtt_publish_sensor_data()

    Motor-Control (Hysterese)

    if 30s vorbei: gc.collect()
    if 60s vorbei: sleep_type=NONE pruefen
    if 1s vorbei:  udp_keepalive zur Gateway

    wdt.feed()                  # Hardware-WDT, sonst Reset in 3s
    time.sleep(0.05)
```

## Astronomische Berechnung

`calculate_optimal_angle()` in `solar_main.py`. Vereinfachte Formel:

```python
declination = 23.45 * sin(360/365 * (day_of_year - 81))
base        = 90 - latitude              # München: 41.9°
equation_of_time = 9.87*sin(2B) - 7.53*cos(B) - 1.5*sin(B)
solar_time  = local_hour + longitude/15 + equation_of_time/60

# Saisonale + tageszeitliche Korrekturen
optimal_angle = base + declination + 0.5*declination + hour_correction
```

Anschließend wird auf `[MIN_ANGLE, MAX_ANGLE]` geclampt. Das Ergebnis bestimmt den Soll-Winkel bis zur nächsten Berechnung (in 10 min).

## Motor-Regelung (asymmetrische Hysterese)

```python
diff = current_angle - target

if motion_dir == 0:
    # Motor steht. Nur starten wenn deutliche Abweichung.
    if abs(diff) > START_TOLERANCE:    # 2.0
        if diff > 0:  rel1.on(); motion_dir = 2  # zu steil -> runter
        else:         rel2.on(); motion_dir = 1  # zu flach -> hoch
else:
    # Motor laeuft. Stop bei minimaler Diff ODER Vorzeichenwechsel.
    overshot = (motion_dir == 2 and diff < 0) or (motion_dir == 1 and diff > 0)
    if abs(diff) < STOP_TOLERANCE or overshot:
        rel1.off(); rel2.off()
        motion_dir = 0
```

- **`START_TOLERANCE = 2.0°`** – verhindert Mikro-Bewegungen bei Sensor-Rauschen
- **`STOP_TOLERANCE = 0.5°`** – stoppt frühzeitig, antizipiert Aktuator-Trägheit
- **Overshoot-Detektion** – wenn das Vorzeichen der Diff kippt, sofort Stopp, kein Zurückreversieren

## Watchdog

ESP8266 hat einen einfachen WDT mit festem Timeout (~3 s, nicht konfigurierbar):

```python
wdt = machine.WDT()          # in init() ganz am Ende aktiviert
...
while True:
    ...
    wdt.feed()               # genau einmal am Ende jeder Iteration
```

Wenn irgendetwas in der Iteration länger als 3 s blockiert (zäher Client im Webserver, MQTT-Hang, I2C-Lockup), kommt das System nicht zu `feed()` und der ESP wird hart resettet.

## Stabilitäts-Tricks (Lessons Learned)

### 1. `mqtt.ping()` darf nicht in jeder Loop-Iteration

```python
# FALSCH (war so):
if mqtt_connected:
    mqtt.ping()              # 20×/Sekunde

# RICHTIG:
if mqtt_connected and time.ticks_diff(now, last_ping) > 30000:
    mqtt.ping()
    last_ping = now
```

Symptom des Bugs: `ECONNRESET` direkt nach Connect, weil Broker den Client als misbehaving stempelt.

### 2. UDP-Keepalive zur Gateway

```python
udp_keepalive.sendto(b'.', (gateway_ip, 9))   # alle 1s
```

Hält das WLAN-Modem aktiv und pflegt die ARP-Tabelle aller Subnet-Hosts – ohne das verliert das ESP ~60% der Inbound-Pakete (klassisches ESP8266-WLAN-Sleep-Problem).

### 3. Web-Timeout kurz halten

```python
conn.settimeout(0.5)         # statt 5.0
```

Zäher Browser-Client darf NICHT 5 s blockieren – sonst hungert der WDT. Ein moderner Browser sendet das Request in <100 ms; alles längere ist verdächtig.

### 4. WDT vor blockierender Operation füttern

```python
def handle_web_request():
    ...
    conn, addr = srv.accept()
    if wdt is not None:
        wdt.feed()                # bevor recv() ggf. 0.5s wartet
    conn.settimeout(0.5)
    request = conn.recv(1024)
```

### 5. `i2c.scan()` vermeiden bei langen I2C-Strecken

`scan()` macht 112 I2C-Transaktionen. Über 2,5 m SoftI2C dauert das >2 s und kann WDT triggern. Stattdessen ein einzelnes `i2c.writeto(addr, b'\x00')` als Probe verwenden.

## MQTT-Subscribe-Flow

```python
def mqtt_on_message(topic, msg):
    if topic.endswith("/EMERGENCY"):
        emergency_mode = (msg in ("on","1","true","yes"))
        if emergency_mode:
            target = MIN_ANGLE
            manual_override = False
        ...

def mqtt_connect():
    mqtt.set_callback(mqtt_on_message)
    mqtt.connect()
    mqtt.subscribe("cmnd/solar/EMERGENCY")
    ...

# in Hauptloop:
mqtt.check_msg()    # nonblocking - ruft Callback wenn Nachricht da
```

Mit `retain=True` gesendete Commands kommen direkt beim Subscribe an – wichtig für Persistenz nach Reboot.

## Sensor-Kalibrierungs-Layer

```python
raw = sensor.get_angle_roll()                    # atan2(accel_y, accel_z)
current_angle = SENSOR_SIGN * (raw - SENSOR_OFFSET)
```

Damit ist die physische Achsen-Orientierung des MPU egal – durch Offset und Vorzeichen wird das auf den echten Winkel zur Horizontalen gemappt. Siehe [calibration.md](calibration.md).

## Webserver

Minimaler HTTP/1.0-Server in einem einzelnen Socket auf Port 80, nonblocking accept. POST-Bodies werden manuell aus dem Request-String geparsed (`minangle=`, `manual=up/down/auto`, `reset`). Kein Routing-Framework, kein Templating – nur eine einzelne HTML-Seite mit `meta http-equiv='refresh' content='5'` für Auto-Reload alle 5 s.

Pro Iteration wird genau ein Request bearbeitet (sequenziell). Reicht für eine Person, die mal F5 drückt – nicht für Last.

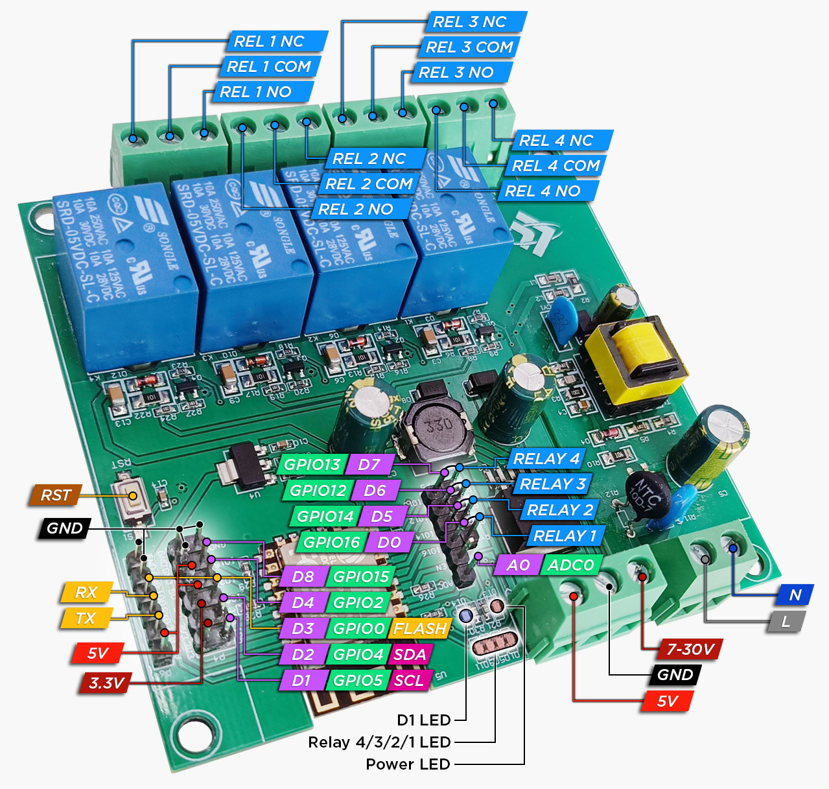
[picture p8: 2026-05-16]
docs/img/x4-peripherals.jpg

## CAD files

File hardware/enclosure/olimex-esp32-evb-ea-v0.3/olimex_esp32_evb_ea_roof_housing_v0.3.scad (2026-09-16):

/*
  Olimex ESP32-EVB-EA Rev. L - roof/ceiling housing for shed interior
  Version: 0.3
  Designed from official OLIMEX Rev-L KiCad board coordinates.

  Installation concept:
    - Base plate is screwed to the underside of the shed roof.
    - PCB hangs below the base on 4 mm standoffs, component side downward.
    - Cover/lid comes from below and is retained by four M3 screws.
    - RST1 is operated by a separate printed side plunger.
    - UEXT1 is accessible through the downward-facing cover floor.
    - PWR1 is accessible through the right side wall.
    - WLAN antenna/pigtail exits through a nominal 10.0 mm front-wall hole.
    - CON1/CON2 actuator screw terminals get a right-side cable/service opening plus two bottom screwdriver windows.
    - USB-UART1 Micro-USB is accessible through the rear wall.
    - No CAN opening is provided.

  Default part for OpenSCAD preview: "preview"
  Export parts with -D 'part="base"', 'part="lid"', 'part="rst_button"', 'fit_test'.
*/

$fn = 64;
selected_part = is_undef(part) ? "preview" : part;

// Source board dimensions
pcb_w = 75.184;
pcb_h = 74.676;
pcb_t = 1.60;

// Rev-L board positions, converted to board-local coordinates from KiCad
// KiCad board minimum: X=69.596, Y=67.056
mh = [
    [71.374,  3.302],
    [71.374, 70.866],
    [ 3.810, 70.866]
];
pwr_pos  = [61.341, 50.513];
uext_pos = [31.750, 61.976];
rst_pos  = [ 5.588, 35.941];
usb_pos  = [63.404, 71.247];
con_pos = [
    [70.904, 29.718],
    [70.904, 14.718]
];

// Housing parameters
case_w = 94.0;
case_y = 92.0;
case_depth = 31.0;
wall = 2.6;
base_t = 3.0;
corner_r = 3.0;

pcb_standoff_h = 4.0;
pcb_z = base_t + pcb_standoff_h;
board_x = (case_w - pcb_w) / 2;
board_y = (case_y - pcb_h) / 2;

rim_clearance = 0.30;
rim_t = 1.40;
rim_h = 3.0;
lid_floor_t = 2.6;

lid_post_d = 6.2;
lid_post_pilot_d = 2.60;
lid_screw_clear_d = 3.40;
lid_post_xy = [
    [5.8, 5.8],
    [case_w-5.8, 5.8],
    [5.8, case_y-5.8],
    [case_w-5.8, case_y-5.8]
];

pcb_post_d = 6.0;
pcb_post_pilot_d = 2.70;
mount_tab_len = 13.0;
mount_tab_w = 18.0;
mount_hole_d = 4.5;
mount_hole_edge = 7.0;
mount_tab_y = [17.0, case_y-17.0];

// Openings / user-adjustable fit values
antenna_hole_d = 10.0;
antenna_x = case_w * 0.48;
antenna_z = 16.0;

pwr_open_y = 11.0;
pwr_open_z = 11.0;
pwr_z0 = pcb_z - 0.5;

uext_open_x = 16.0;
uext_open_y = 7.0;

usb_open_x = 13.0;
usb_open_z = 8.5;
usb_z0 = pcb_z + pcb_t - 1.0;

terminal_side_clear = 0.8;
terminal_block_half_len = 8.25;
terminal_side_z0 = pcb_z + pcb_t - 1.0;
terminal_side_z = 13.5;
terminal_floor_x = 13.0;
terminal_floor_y = 14.0;
terminal_side_y = abs(con_pos[0][1]-con_pos[1][1]) + 2*(terminal_block_half_len + terminal_side_clear);

rst_hole_d = 4.2;
rst_axis_z = pcb_z + 1.7;
rst_cap_d = 8.0;
rst_cap_t = 2.4;
rst_shaft_d = 3.55;
rst_shaft_len = 11.0;
rst_barb_d = 4.55;
rst_barb_h = 1.0;

ventilation = true;
vent_slot_len = 18.0;
vent_slot_w = 2.2;

module rounded_tab(size=[13,18,3], r=3) {
    hull() {
        for (x=[r, size[0]-r], y=[r, size[1]-r])
            translate([x,y,0]) cylinder(h=size[2], r=r);
    }
}

module ring_rect(outer=[88,86], t=1.4, h=3) {
    difference() {
        cube([outer[0], outer[1], h]);
        translate([t,t,-0.1]) cube([outer[0]-2*t, outer[1]-2*t, h+0.2]);
    }
}

module base() {
    difference() {
        union() {
            cube([case_w, case_y, base_t]);
            for (yy = mount_tab_y) {
                translate([-mount_tab_len, yy-mount_tab_w/2, 0])
                    rounded_tab([mount_tab_len+1.0, mount_tab_w, base_t], corner_r);
                translate([case_w-1.0, yy-mount_tab_w/2, 0])
                    rounded_tab([mount_tab_len+1.0, mount_tab_w, base_t], corner_r);
            }
            translate([wall+rim_clearance, wall+rim_clearance, base_t])
                ring_rect(
                    [case_w-2*(wall+rim_clearance), case_y-2*(wall+rim_clearance)],
                    rim_t, rim_h
                );
            for (p = mh)
                translate([board_x+p[0], board_y+p[1], base_t])
                    cylinder(h=pcb_standoff_h, d=pcb_post_d);
            for (p = lid_post_xy)
                translate([p[0], p[1], base_t])
                    cylinder(h=case_depth-lid_floor_t-base_t-1.0, d=lid_post_d);
        }

        for (yy = mount_tab_y) {
            translate([-mount_hole_edge, yy, -0.5])
                cylinder(h=base_t+1.0, d=mount_hole_d);
            translate([case_w+mount_hole_edge, yy, -0.5])
                cylinder(h=base_t+1.0, d=mount_hole_d);
        }
        for (p = mh)
            translate([board_x+p[0], board_y+p[1], base_t-0.2])
                cylinder(h=pcb_standoff_h+0.5, d=pcb_post_pilot_d);
        for (p = lid_post_xy)
            translate([p[0], p[1], case_depth-lid_floor_t-9.0])
                cylinder(h=10.0, d=lid_post_pilot_d);
    }
}

module lid_assembly() {
    pwr_y_world = board_y + pwr_pos[1];
    uext_x_world = board_x + uext_pos[0];
    uext_y_world = board_y + uext_pos[1];
    rst_y_world = board_y + rst_pos[1];
    usb_x_world = board_x + usb_pos[0];
    con_x_world = board_x + con_pos[0][0];
    con_y_lo = board_y + min(con_pos[0][1], con_pos[1][1]) - terminal_block_half_len - terminal_side_clear;
    con_y_hi = board_y + max(con_pos[0][1], con_pos[1][1]) + terminal_block_half_len + terminal_side_clear;

    difference() {
        translate([0,0,base_t])
            cube([case_w, case_y, case_depth-base_t]);
        translate([wall, wall, base_t-0.2])
            cube([case_w-2*wall, case_y-2*wall,
                  case_depth-base_t-lid_floor_t+0.2]);
        translate([case_w-wall-0.2,
                   pwr_y_world-pwr_open_y/2,
                   pwr_z0])
            cube([wall+0.6, pwr_open_y, pwr_open_z]);
        translate([case_w-wall-0.2, con_y_lo, terminal_side_z0])
            cube([wall+0.6, con_y_hi-con_y_lo, terminal_side_z]);
        translate([usb_x_world-usb_open_x/2, case_y-wall-0.2, usb_z0])
            cube([usb_open_x, wall+0.6, usb_open_z]);
        translate([-0.5, rst_y_world, rst_axis_z])
            rotate([0,90,0])
                cylinder(h=wall+1.0, d=rst_hole_d);
        translate([antenna_x, wall+0.5, antenna_z])
            rotate([90,0,0])
                cylinder(h=wall+1.0, d=antenna_hole_d);
        translate([uext_x_world-uext_open_x/2,
                   uext_y_world-uext_open_y/2,
                   case_depth-lid_floor_t-0.3])
            cube([uext_open_x, uext_open_y, lid_floor_t+0.6]);
        for (cp = con_pos)
            translate([con_x_world-terminal_floor_x/2,
                       board_y+cp[1]-terminal_floor_y/2,
                       case_depth-lid_floor_t-0.3])
                cube([terminal_floor_x, terminal_floor_y, lid_floor_t+0.6]);
        for (p = lid_post_xy)
            translate([p[0], p[1], case_depth-lid_floor_t-0.3])
                cylinder(h=lid_floor_t+0.6, d=lid_screw_clear_d);
        if (ventilation) {
            for (yy=[24, 31, 38])
                translate([case_w/2-vent_slot_len/2, yy-vent_slot_w/2,
                           case_depth-lid_floor_t-0.3])
                    cube([vent_slot_len, vent_slot_w, lid_floor_t+0.6]);
        }
    }
}

module lid() {
    translate([0,case_y,case_depth])
        rotate([180,0,0])
            lid_assembly();
}

module rst_button() {
    union() {
        cylinder(h=rst_cap_t, d=rst_cap_d);
        translate([0,0,rst_cap_t])
            cylinder(h=rst_shaft_len-rst_barb_h, d=rst_shaft_d);
        translate([0,0,rst_cap_t+rst_shaft_len-rst_barb_h])
            cylinder(h=rst_barb_h, d1=rst_shaft_d, d2=rst_barb_d);
    }
}

module pcb_mock() {
    difference() {
        linear_extrude(pcb_t)
            difference() {
                square([pcb_w,pcb_h]);
                translate([-0.1,-0.1]) square([19.658,6.196]);
                translate([58.674,pcb_h-1.116]) square([9.525,1.216]);
            }
        for (p=mh)
            translate([p[0],p[1],-0.1]) cylinder(h=pcb_t+0.2,d=3.3);
    }
}

module component_markers() {
    translate([board_x+uext_pos[0]-8, board_y+uext_pos[1]-5, pcb_z+pcb_t])
        cube([16,10,8]);
    translate([board_x+pwr_pos[0]-5, board_y+pwr_pos[1]-6, pcb_z+pcb_t])
        cube([18,12,10]);
    for (cp = con_pos)
        translate([board_x+cp[0]-4.2, board_y+cp[1]-8.25, pcb_z+pcb_t])
            cube([8.4,16.5,10.0]);
    translate([board_x+usb_pos[0]-4.0, board_y+usb_pos[1]-3.4, pcb_z+pcb_t])
        cube([8.0,6.8,3.2]);
    translate([board_x+rst_pos[0]-3, board_y+rst_pos[1]-2, pcb_z+pcb_t])
        cube([6,4,2.5]);
}

module rst_button_assembly() {
    rst_y_world = board_y + rst_pos[1];
    translate([-rst_cap_t, rst_y_world, rst_axis_z])
        rotate([0,90,0])
            rst_button();
}
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

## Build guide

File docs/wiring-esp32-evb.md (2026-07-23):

---
title: Wiring-Übersicht ESP32-EVB
---

# Wiring-Übersicht — Olimex ESP32-EVB-EA

Alle vier Schaltbilder der Migration **ESP12F-Relay-X4 v1.2 → Olimex ESP32-EVB-EA Rev.L**
auf einer Seite — zum Ausdrucken oder als Werkbank-Referenz auf dem Tablet.

Die ausführliche Doku mit Bauteilliste, Auslegung und Checkliste steht in
[Hardware-Migration ESP12F → Olimex ESP32-EVB-EA](hardware-migration-esp32-evb.html).

> ⚠️ **Die eine Regel, die alles killt:** Der Olimex ist **strikt 5 V**
> (onboard TPS62A02, abs. Max 6.5 V). 12 V an DC-Jack, UEXT Pin 1 oder Micro-USB
> zerstört den Regler sofort. Deshalb der Mini-360-Split in Diagramm 2a.

<style>
.fms-legend { display:flex; flex-wrap:wrap; gap:14px; margin:18px 0 26px; padding:0; list-style:none; }
.fms-legend li { display:flex; align-items:center; gap:7px; font-size:0.9em; }
.fms-swatch { display:inline-block; width:15px; height:15px; border-radius:3px; border:1px solid rgba(0,0,0,.35); flex:0 0 auto; }
figure.fms-fig { margin:0 0 34px; padding:0; }
figure.fms-fig .fms-frame { background:#fff; border:1px solid #d8d8d8; border-radius:6px; padding:10px; overflow-x:auto; }
figure.fms-fig img { display:block; width:100%; height:auto; }
figure.fms-fig figcaption { font-size:0.86em; color:#555; margin-top:7px; line-height:1.45; }
</style>

**Farbcode in allen Diagrammen:**

<ul class="fms-legend">
  <li><span class="fms-swatch" style="background:#ffe0e0;border-color:#c00;"></span> 12 V + (Plus)</li>
  <li><span class="fms-swatch" style="background:#e0e0ff;border-color:#000055;"></span> 12 V − (Minus)</li>
  <li><span class="fms-swatch" style="background:#fff2b3;border-color:#c97a00;"></span> 5 V / Logik-Rail</li>
  <li><span class="fms-swatch" style="background:#e8f5e8;border-color:#2a7a2a;"></span> Aktuator-Last</li>
  <li><span class="fms-swatch" style="background:#cce4ff;border-color:#004a99;"></span> I²C / Sensor</li>
</ul>

---

## 1 — IST-Zustand: ESP12F-Relay-X4 v1.2

<figure class="fms-fig">
  <div class="fms-frame">
    <a href="img/hardware-esp32-evb/01_ist_esp12f.svg" title="In voller Größe öffnen">
      Blockschaltbild des bisherigen Aufbaus mit ESP12F-Relay-X4: 12 V direkt an die VIN-Klemme, Boardregler auf 5 V und 3.3 V, Relais K1 an GPIO16 und K2 an GPIO14, MPU-6050 über GPIO4/GPIO5.
    </a>
  </div>
  <figcaption>
    Der bisherige Aufbau: 12 V gehen <b>direkt</b> an die VIN-Klemme (DC 7–30 V), der
    Boardregler zieht selbst auf 5 V und 3.3 V herunter. K1 (GPIO16, „Motor Runter") und
    K2 (GPIO14, „Motor Hoch") schalten die Aktuator-Adern in Polaritätsumkehr.
    MPU-6050 hängt an GPIO4 (SDA) / GPIO5 (SCL).
  </figcaption>
</figure>

---

## 2a — SOLL: Power-Pfad mit 12 V-Split

<figure class="fms-fig">
  <div class="fms-frame">
    <a href="img/hardware-esp32-evb/02a_soll_power.svg" title="In voller Größe öffnen">
      Power-Pfad des neuen Aufbaus: 12 V-Netzteil auf zwei WAGO-221-Klemmen, Zweig A über Mini-360-Buck auf 5,0 V und DC-Hohlstecker zum Olimex-DC-Jack, Zweig B direkt auf REL1-COM und REL2-COM.
    </a>
  </div>
  <figcaption>
    Die 12 V-Zuleitung wird an zwei WAGO 221 (3-Leiter) aufgeteilt.
    <b>Zweig A (Logik):</b> 12 V → Mini-360 → auf exakt 5.00 V getrimmt →
    DC-Hohlstecker 5.5 × 2.1 mm (Innen = +, Ring = −) → Olimex DC-Jack →
    onboard TPS62A02 → 5 V / 3.3 V.
    <b>Zweig B (Last):</b> 12 V+ direkt an REL1-COM, 12 V− direkt an REL2-COM.
    Gemeinsame Masse ergibt sich automatisch — beide Zweige kommen aus derselben Quelle,
    ein extra GND-Kabel ist nicht nötig.
  </figcaption>
</figure>

---

## 2b — SOLL: Signal- und Lastpfad

<figure class="fms-fig">
  <div class="fms-frame">
    <a href="img/hardware-esp32-evb/02b_soll_signals.svg" title="In voller Größe öffnen">
      Signalpfad des neuen Aufbaus: ESP32 steuert REL1 über GPIO32 und REL2 über GPIO33 in Polarity-Reverse zum Linear-Aktuator, MPU-6050 vierdrahtig am UEXT-Stecker Pin 1, 2, 5 und 6.
    </a>
  </div>
  <figcaption>
    Der ESP32 steuert die beiden <b>Onboard</b>-Relais: REL1 = GPIO32 („Motor Runter"),
    REL2 = GPIO33 („Motor Hoch"). Die Aktuator-Adern hängen in Polarity-Reverse an NO/NC —
    die zwei externen Relais des alten Aufbaus entfallen komplett.
    Der MPU-6050 hängt vierdrahtig am UEXT-Stecker (Pin 1/2/5/6), Pull-ups sind onboard.
  </figcaption>
</figure>

### UEXT-Pinout (Sicht von oben aufs Board, Pin 1 markiert)

```
   1 +3.3V    2 GND
   3 TXD      4 RXD
   5 SCL      6 SDA    ←── MPU-6050 hier
   7 MISO     8 MOSI
   9 SCK     10 SS
```

| MPU-6050 | ALT — ESP12F-Relay-X4 | NEU — Olimex UEXT |
|---|---|---|
| VCC | 3V3 Stiftleiste | **UEXT Pin 1 (+3.3 V)** |
| GND | GND Stiftleiste | **UEXT Pin 2 (GND)** |
| SCL | GPIO5 (D1) | **UEXT Pin 5 → GPIO16** |
| SDA | GPIO4 (D2) | **UEXT Pin 6 → GPIO13** |
| AD0 | an GND (Adr. 0x68) | an GND (unverändert) |

---

## 3 — Klemmen-Detail

<figure class="fms-fig">
  <div class="fms-frame">
    <a href="img/hardware-esp32-evb/03_klemmen_detail.svg" title="In voller Größe öffnen">
      Klemmenplan: WAGO A für 12 V plus und WAGO B für 12 V minus, Mini-360 mit VIN und VOUT, DC-Hohlstecker Innen plus und Ring minus, sowie die Belegung der Olimex-Schraubklemmen REL1-COM, REL1-NO, REL1-NC, REL2-COM, REL2-NO und REL2-NC.
    </a>
  </div>
  <figcaption>
    Ader für Ader, so wie es in die Klemmen geht. Bei sehr breitem Diagramm:
    Bild anklicken öffnet die SVG in voller Auflösung — SVG ist verlustfrei zoombar.
  </figcaption>
</figure>

### Klemmenbelegung als Tabelle

| Funktion | ALT — ESP12F-Relay-X4 | NEU — Olimex ESP32-EVB-EA |
|---|---|---|
| Steuerung „Motor Runter" | GPIO16 → K1-Spule | **GPIO32 (REL1)** — onboard |
| Steuerung „Motor Hoch" | GPIO14 → K2-Spule | **GPIO33 (REL2)** — onboard |
| 12 V **+** | K1-COM | **REL1-COM** |
| 12 V **−** | K2-COM | **REL2-COM** |
| Aktuator **+** | K1-NO | **REL1-NO + REL2-NC** |
| Aktuator **−** | K2-NO | **REL2-NO + REL1-NC** |
| Board-Versorgung | 12 V an VIN-Klemme | **5.0 V an DC-Jack** (aus Mini-360) |

**Wenn die Motorrichtung verkehrt ist:** entweder `PIN_RELAY1` / `PIN_RELAY2` in `env.py`
tauschen **oder** die Aktuator-Adern mechanisch in den Klemmen kreuzen — nicht beides,
sonst hebt es sich auf.

---

## Sicherheits-Reminder vor dem Power-On

- **Antenne zuerst.** IPEX-Pigtail eingerastet + SMA-Stab aufgeschraubt **vor** dem Einschalten — HF-Reflexion ohne Antenne schädigt das Modul.
- **Mini-360 auf der Werkbank trimmen**, ohne Olimex am Ausgang, mit Multimeter auf 5.00 V. Poti **nie unter Last** verstellen (Overshoot möglich).
- **Aktuator-Adern beim Erstboot abklemmen** — GPIO32/33 wackeln beim Boot, die Relais klicken.
- **Nie 12 V** in irgendeinen Anschluss des Olimex.
- **Keine 230 V** auf die Olimex-Relais — der Aufbau ist mechanisch nicht dafür isoliert.
- Der EVB hat **kein PoE** über RJ45 (das ist die separate `ESP32-POE`-Variante).

---

## Quellen

- [ESP32-EVB Rev.L Schaltplan (PDF, OLIMEX)](https://github.com/OLIMEX/ESP32-EVB/blob/master/HARDWARE/REV-L/ESP32-EVB_Rev_L.pdf)
- [ESP32-EVB User Manual (PDF, OLIMEX)](https://github.com/OLIMEX/ESP32-EVB/blob/master/DOCS/ESP32-EVB-user-manual.pdf)
- [TI TPS62A02 Datenblatt](https://www.ti.com/product/TPS62A02A)

[← zurück zur Startseite](../)

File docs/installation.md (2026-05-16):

---
title: Installation
---

# Installation Schritt-für-Schritt

Ziel: Von „nichts" zu „läuft im Garten" in ~2 Stunden.

## Voraussetzungen

Auf deinem PC:
- **Python 3.10+**
- **pip** Pakete: `mpremote`, `mpy-cross`, `esptool` (alle pip-installierbar)
- **MicroPython-Firmware** für ESP8266: [micropython.org/download/ESP8266_GENERIC](https://micropython.org/download/ESP8266_GENERIC/)
- USB-zu-TTL-Adapter (3,3 V kompatibel, z.B. CP2102, FT232 oder das Adapter-Modul aus dem ESP12F-Relay-Board-Set)
- MQTT-Broker im selben Netz (Mosquitto, oder embedded in Home Assistant)

```bash
pip install mpremote mpy-cross esptool paho-mqtt
```

## Schritt 1: MicroPython auf den ESP12F flashen

Das ESP12F-Relay-X4-Board wird über das mitgelieferte USB-Adapter-Modul angeschlossen (steckt seitlich auf die Pinleiste). Position des Jumpers `Run/Prog` auf `Prog` setzen für Flash-Modus.

```bash
# COM-Port ermitteln (Windows)
mode

# Flash loeschen
esptool --port COM3 erase_flash

# Firmware schreiben (MicroPython 1.28 oder neuer)
esptool --port COM3 --baud 460800 write_flash --flash_size=detect 0 ESP8266_GENERIC-20251213-v1.28.0.bin
```

Jumper zurück auf `Run`, USB neu anstecken. Mit `mpremote` testen:

```bash
python -m mpremote connect COM3
# Es sollte ein MicroPython-Prompt erscheinen (>>>)
```

## Schritt 2: Repo klonen

```bash
git clone https://github.com/icepaule/followmysun.git
cd followmysun/src
```

## Schritt 3: Konfiguration

`env.example.py` nach `env.py` kopieren und die Werte einfüllen:

```python
WIFI_SSID     = "DeinWLAN"
WIFI_PASSWORD = "DeinPasswort"
MQTT_SERVER   = "192.168.178.50"      # IP deines Brokers
MQTT_USER     = "user"
MQTT_PASSWORD = "passwort"
WEBREPL_PASSWORD = "deinpwd"           # 4–9 Zeichen, frei waehlbar
HOSTNAME      = "solar"
```

> **Wichtig:** Die echte `env.py` ist in `.gitignore` ausgeschlossen und wird **nie** ins Git-Repo commitet.

## Schritt 4: Bytecode kompilieren

Der Hauptcode (`solar_main.py`) ist mit ~33 KB zu groß zum Parsen auf dem ESP8266 (Heap nur ~35 KB). Wir kompilieren ihn mit `mpy-cross` zu Bytecode:

```bash
python -m mpy_cross solar_main.py
python -m mpy_cross mpu6050.py
```

Ergebnis: `solar_main.mpy` (~12 KB) und `mpu6050.mpy` (~1 KB).

## Schritt 5: Dateien hochladen (per USB)

```bash
python -m mpremote connect COM3 cp boot.py :boot.py
python -m mpremote connect COM3 cp main.py :main.py
python -m mpremote connect COM3 cp env.py :env.py
python -m mpremote connect COM3 cp mpu6050.mpy :mpu6050.mpy
python -m mpremote connect COM3 cp solar_main.mpy :solar_main.mpy
```

Verifizieren:
```bash
python -m mpremote connect COM3 ls
# erwartet: boot.py env.py main.py mpu6050.mpy solar_main.mpy
```

## Schritt 6: Erster Boot

```bash
python -m mpremote connect COM3
# Im Prompt: Ctrl-D fuer Soft-Reset
```

Erwartet:
```
ESP12F Solar-Steuerung
WLAN OK: 192.168.178.92
Modem-Sleep AUS (sleep_type=NONE) nach Connect
MQTT verbunden mit 192.168.178.50:1883
Webserver läuft auf Port 80
Watchdog aktiv (~3s Timeout)
System bereit - Starte Hauptschleife
Sensor: 32.0° (Ziel: 35.0°)
```

Wenn das durchläuft: **System läuft.**

## Schritt 7: Webseite öffnen

`http://<ESP-IP>/` im Browser. Zeigt aktuellen Winkel, Soll-Winkel, Motorstatus.

## Schritt 8: Kalibrierung

Die `SENSOR_OFFSET` und `SENSOR_SIGN` in `env.py` sind nur Schätzwerte und müssen einmalig eingemessen werden. Siehe **[calibration.md](calibration.md)**.

## Spätere Updates – via WebREPL ohne USB

Wenn das Gerät erstmal im Feld ist, geht der Update-Weg übers WLAN:

```bash
# Code lokal aendern, neu kompilieren
python -m mpy_cross solar_main.py

# Hochladen
python webrepl_cli.py -p DEIN_WEBREPL_PWD solar_main.mpy <IP>:/solar_main.mpy

# Reboot via WebREPL (Browser unter https://micropython.org/webrepl/)
# Connect ws://<IP>:8266/ → "import machine; machine.reset()"
```

## Troubleshooting

| Symptom | Mögliche Ursache | Fix |
|---|---|---|
| `MemoryError` beim Boot | `.py` statt `.mpy` hochgeladen | mit `mpy_cross` kompilieren |
| Webseite Timeout, MQTT funktioniert | WLAN-Power-Save | bereits gefixt in `solar_main.py` ([siehe Lessons-Learned im README](../README.md#lessons-learned)) |
| Sensor liest Werte > 90° bei flachem Panel | MPU-Achsen 90° verdreht | `SENSOR_OFFSET` anpassen, [calibration.md](calibration.md) |
| Motor läuft permanent in eine Richtung | Sensor falsch herum, `SENSOR_SIGN` umdrehen | `SENSOR_SIGN = -1` setzen |
| ESP rebootet alle paar Sekunden | WDT triggert wegen langsamem `i2c.scan()` oder anderem Block | siehe Lessons Learned |
| MQTT `ECONNRESET` direkt nach Connect | Broker stempelt zu viele `ping()` als Misbehavior | bereits gefixt (Throttle auf 1×/30 s) |

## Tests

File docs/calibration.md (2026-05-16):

---
title: Kalibrierung
---

# Kalibrierung MPU-6050

Der MPU misst Roll als Winkel zwischen Y- und Z-Achse. Je nachdem wie das Modul physisch eingebaut ist, stimmt der Roh-Wert nicht 1:1 mit dem echten Panel-Winkel zur Horizontalen. Zwei Parameter in `env.py` machen das geradeziehen ohne dass du am Sensor schrauben musst:

```python
SENSOR_OFFSET = 87.3   # Nullpunkt-Verschiebung
SENSOR_SIGN   = 1      # +1 oder -1, je nach Achsen-Orientierung

# Umrechnung im Code:
# echter_winkel = SENSOR_SIGN * (raw - SENSOR_OFFSET)
```

## Einmessverfahren – 2 Datenpunkte reichen

Du brauchst zwei mechanisch klare Positionen:
- **Aktuator komplett eingefahren** (Panel liegt flach auf dem Dach)
- **Aktuator komplett ausgefahren** (Endschalter erreicht)

Die echten Winkel beider Positionen musst du messen oder ableiten:
- **Eingefahren** = Dachneigung (z.B. 32° bei meinem Gartenhaus, mit Wasserwaage / Handy-Libellen-App messen)
- **Ausgefahren** = Dachneigung + Aktuator-Hub-Winkel (bei mir 58.7°, mit Wasserwaage am Panel gemessen)

### Schritt 1: Aktuator einfahren, Roh-Wert ablesen

Über Webseite oder MQTT:
```bash
mosquitto_sub -h <broker> -u user -P pw \
  -t tele/solar/SENSOR/PanelAngleRaw -v
```

Beispiel-Ablesung: `raw_min = 119.3` bei echtem Winkel 32°.

### Schritt 2: Aktuator ausfahren, Roh-Wert ablesen

Auf der Webseite: `⬆️` klicken, warten bis Aktuator am Endschalter steht (Wert bewegt sich nicht mehr, dauert ~30–60 s je nach Hub), dann Roh-Wert ablesen.

Beispiel: `raw_max = 146.0` bei echtem Winkel 58.7°.

### Schritt 3: Vorzeichen prüfen

```
raw_max > raw_min  →  SENSOR_SIGN = +1   (steigender Raw = steigender Winkel)
raw_max < raw_min  →  SENSOR_SIGN = -1   (fallender Raw = steigender Winkel)
```

In meinem Beispiel: `146.0 > 119.3` → **SIGN = +1**.

### Schritt 4: Offset berechnen

```
SENSOR_OFFSET = raw_min - (echter_winkel_min * SIGN)
              = 119.3 - 32.0
              = 87.3
```

### Schritt 5: MAX_ANGLE setzen

```
MAX_ANGLE = SIGN * (raw_max - SENSOR_OFFSET)
          = 1 * (146.0 - 87.3)
          = 58.7
```

In `env.py` eintragen, speichern, hochladen, ESP rebooten.

### Verifikation

Webseite öffnen:
- Bei eingefahrenem Aktuator: Aktuell-Wert ≈ deine `MIN_ANGLE`
- Bei ausgefahrenem Aktuator: Aktuell-Wert ≈ deine `MAX_ANGLE`
- Bereich-Anzeige zeigt `32.0° – 58.7°`

## Häufige Fälle

| Beobachtung | Diagnose | Fix |
|---|---|---|
| Raw bei eingefahren ist ~120, sollte ~32 sein | 90°-Achsen-Verdrehung im Sensor | `OFFSET = raw - real`, hier ~88 |
| Aktuator fährt aus, Raw wird **kleiner** | Y-Achse zeigt zur Unterkante | `SENSOR_SIGN = -1` |
| Beim Bewegen zwischen Endlagen springt der Wert wild | Z-Achse nicht senkrecht zum Panel | mechanisch umorientieren – Kalibrierung kann das nicht retten |
| Werte stabil aber ±2° Drift | Normal für MPU-6050 ohne Gyro-Fusion | mit der `tolerance`-Konstante im Code abfangen (default 2°) |

## Toleranzen und Tiefpass

Der Code hat eine asymmetrische Hysterese in `solar_main.py`:

```python
START_TOLERANCE = 2.0   # Motor startet erst ab dieser Abweichung
STOP_TOLERANCE  = 0.5   # Motor stoppt sobald innerhalb dieser Grenze
```

Das verhindert das Hin-und-her-Klacken der Relais bei kleinen Sensor-Rauschen. Wenn du noch ruhigeres Verhalten willst (z.B. bei windigem Aufbau), bietet sich ein Moving-Average über die letzten 5 Messungen an (nicht standardmäßig drin, kann als Erweiterung eingebaut werden).

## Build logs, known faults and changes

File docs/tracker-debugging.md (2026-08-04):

---
title: Tracker-Debugging und Quellbasis
---

# Tracker-Debugging und Quellbasis

Diese Seite sammelt die für den Solar-Tracker aktuell relevante Quellbasis, die Laufzeit-Variante und die wichtigsten Hinweise für zukünftige Änderungen und Debugging-Schritte.

## Aktuelle Laufzeit-Variante

Der Tracker läuft im Feld nicht direkt aus der lesbaren Python-Datei, sondern aus der kompilierten MicroPython-Datei:

- `solar_main.mpy` – aktive Laufzeitdatei auf dem Tracker
- `src/solar_main.py` – lesbare Quellbasis für die Dokumentation und spätere Änderungen
- `src/env.py` – lokale Konfiguration, inklusive Pins, Sensor-Kalibrierung und MQTT-/WebREPL-Setup
- `src/mpu6050.py` – Sensor-Treiber für den MPU-6050
- `src/boot.py` – Start- und Boot-Logik
- `src/main.py` – Loader, der `solar_main.mpy` lädt

Die wichtigste Referenz für zukünftige Änderungen ist dabei die aktuelle Quelle in [src/solar_main.py](../src/solar_main.py) zusammen mit [src/env.example.py](../src/env.example.py). Diese Dateien bilden die Basis für den aktuellen Tracker-Stand im Repo.

> Für die öffentliche Doku sollten die Werte aus `env.py` nur ohne sensible Zugangsdaten beschrieben werden. WLAN-, MQTT- und WebREPL-Credentials bleiben lokal und werden nicht im GitHub-Repo veröffentlicht.

## Was die aktive Quellbasis leistet

Die aktuelle Quellbasis des Trackers enthält im Kern:

- Astronomische Soll-Winkel-Berechnung
- Abgleich des aktuellen Winkelstands gegen den Sollwert
- Relaisgesteuerte Bewegung des Aktuators
- MQTT-Übermittlung von Status- und Sensorwerten
- Notfallmodus über MQTT
- Webserver für lokale Steuerung
- Watchdog-/Stabilitäts-Logik gegen Hänger

## Für zukünftige Debugging-Szenarien nützlich

Wenn der Tracker später erneut untersucht oder angepasst werden soll, ist diese Reihenfolge sinnvoll:

1. `src/solar_main.py` – eigentliche Regelungslogik verstehen
2. `src/env.py` – Konfiguration prüfen
3. `src/mpu6050.py` – Sensorwerte und Kalibrierung prüfen
4. `src/boot.py` – Startverhalten und WebREPL-Initialisierung prüfen
5. `src/main.py` – Loader-Mechanik sicherstellen

## Typische Debugging-Checkliste

- Ist `solar_main.mpy` wirklich die Datei, die auf dem Gerät läuft?
- Wurde nach Änderungen an `src/solar_main.py` auch neu mit `mpy_cross` kompiliert?
- Ist die Sensor-Kalibrierung (`SENSOR_OFFSET`, `SENSOR_SIGN`) korrekt?
- Läuft das MQTT-Handling stabil, oder sind Reconnects/Timeouts der Fehler?
- Funktioniert der Webserver und der WebREPL lokal im Netzwerk?
- Ist der Notfallmodus über MQTT weiterhin zuverlässig?

## Praktischer Ablauf für Änderungen

```bash
cd src
python -m mpy_cross solar_main.py
python -m mpy_cross mpu6050.py
```

Anschließend die neu erzeugten `.mpy`-Dateien auf den Tracker hochladen und mit einem Reboot prüfen.

## Hinweise zur Dokumentation

Für zukünftige Dokumentations- und Debug-Aufgaben sollte die Doku folgende Punkte enthalten:

- aktuelle Funktionsweise des Trackers
- verwendete Pin-Belegung
- Sensor-Kalibrierung und mechanische Endlagen
- MQTT-Topics und Bedeutung
- relevante Fehlermuster und bekannte Fixes
- Arbeitsweise von Webserver und WebREPL

Damit bleibt die Dokumentation als Wartungs- und Debug-Referenz auch über längere Zeit hinweg nutzbar.

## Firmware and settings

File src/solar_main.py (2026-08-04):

# ESP32 Solar Panel Controller mit MPU-6050, MQTT, NTP und Webinterface
#
# Hardware:
# - MPU-6050 (GY-521) Gyro/Accel Sensor zur Winkelmessung
# - 2x Relays zur Motorsteuerung (Hoch/Runter)
# - ESP32 mit WLAN-Verbindung
#
# Funktionen:
# - Automatische Sonnenwinkel-Berechnung basierend auf Astronomie
# - NTP-Zeitaktualisierung mit präziser deutscher Zeitzone (MEZ/MESZ)
# - MQTT-Übertragung aller Sensordaten und Status
# - Webinterface zur manuellen Steuerung und Überwachung
# - WebREPL für Fernwartung
#
# Autor: Solar Controller v2.1
# Datum: 24.05.2025

import machine
import time
import network
import gc
import esp
import socket
import errno
import math
import uselect
import ujson
import uos
from umqtt.simple import MQTTClient
from mpu6050 import MPU6050

import env
print("env.py geladen")
# WebREPL wird bereits in boot.py gestartet.

# =============================================================================
# GLOBALE VARIABLEN UND KONFIGURATION
# =============================================================================

# Hardware-Objekte
sensor = None               # MPU-6050 Gyroskop/Accel-Sensor-Objekt
rel1 = None                # Relay 1 (Motor Runter)
rel2 = None                # Relay 2 (Motor Hoch)
mqtt = None                # MQTT-Client-Objekt
srv = None                 # Webserver-Socket-Objekt
wdt = None                 # Hardware-Watchdog (None bis init() erfolgreich war)

# Sensor- und Steuerungsdaten
current_angle = None       # Kalibrierter Panel-Winkel in Grad zur Horizontalen
current_angle_raw = None   # Roh-MPU-Wert (atan2 unkalibriert) - fuer Kalibrierung
angle = 35.0              # Berechneter optimaler Sonnenwinkel in Grad
target = 30.0             # Ziel-Neigungswinkel basierend auf Sonnenwinkel in Grad
tolerance = 2.0           # Toleranz für Winkelabweichung in Grad
motion_dir = 0            # Motor-Richtung: 0=Stopp, 1=Hoch, 2=Runter
manual_override = False   # Manueller Modus aktiv (True/False)
emergency_mode = False    # Notfall: Panel SOFORT auf MIN_ANGLE (Sturm-Schutz)

# Zeitsteuerung
sunset = 18               # Sonnenuntergang Stunde (lokale Zeit, grobes Fallback)
sunrise = 6               # Sonnenaufgang Stunde (lokale Zeit, grobes Fallback)

# Tracking-Aktiv-Fenster: Panel-Nachfuehrung laeuft nur zwischen TRACK_START_H
# und (echter Sonnenuntergang - TRACK_END_BEFORE_SUNSET_H). Davor und danach
# bleibt das Panel flach auf MIN_ANGLE liegen (Stromertrag in Randzeiten
# rechtfertigt die Verfahrwege nicht und reduziert Verschleiss/Risiko).
TRACK_START_H = 8.0
TRACK_END_BEFORE_SUNSET_H = 1.0

# MQTT-Status und Timing
mqtt_connected = False    # MQTT-Verbindungsstatus
last_mqtt_publish = 0     # Letzter MQTT-Publish Zeitstempel
mqtt_publish_interval = 30000  # MQTT-Publish Intervall in ms (30 Sekunden)
last_mqtt_connect_attempt = 0  # Letzter MQTT-Verbindungsversuch
mqtt_reconnect_interval = 60000  # MQTT-Reconnect Intervall in ms (60 Sekunden)
last_mqtt_ping = 0        # Letzter MQTT-Ping (Throttle - sonst 20x/s)
mqtt_ping_interval = 30000     # MQTT-Ping nur alle 30 Sekunden

# MQTT-Socket-Timeout in Sekunden. umqtt.simple legt den Socket OHNE Timeout
# an -> ein publish()/ping() auf eine tote bzw. halb-offene TCP-Verbindung
# blockiert dann *unendlich* in socket.send(). Fatal: waehrend eines
# blockierenden Syscalls fuettert das SDK beide Watchdogs (HW + Soft) weiter,
# es kommt also KEIN Reset - das Geraet haengt komplett und nur ein physischer
# Reset hilft. Genau dieses Symptom ("morgens haengt die Steuerung") killt der
# Timeout: send() wirft nach Ablauf ein OSError, das die vorhandene
# Fehlerbehandlung faengt -> Reconnect + Health-Watchdog greifen wieder.
# Bewusst kurz (< ~3,2 s Soft-WDT-Fenster), damit der Loop nach einem Stall
# weiterlaeuft, bevor irgendein Watchdog zuschlaegt.
MQTT_SOCKET_TIMEOUT = 2

# Netzwerk-Keepalive (UDP an Gateway): haelt WLAN-MAC aktiv,
# pflegt ARP-Cache der anderen Hosts im Subnet.
udp_keepalive = None      # UDP-Socket fuer Outbound-Keepalive
udp_keepalive_gw = None   # Gateway-IP (str) fuer das sendto

# Connectivity-Watchdog: Der Hardware-WDT (3s) faengt nur CPU-Hangs.
# Ein Netzwerk-Stall (WLAN noch "connected", aber MQTT-Socket tot, Loop
# laeuft munter weiter und fuettert den WDT) ueberlebt den HW-WDT.
# Darum tracken wir den letzten erfolgreichen MQTT-Publish und reseten
# das System wenn zu lange Funkstille herrscht.
last_successful_publish = 0          # ticks_ms() des letzten erfolgreichen publish
last_health_check = 0                # ticks_ms() der letzten Health-Pruefung
HEALTH_CHECK_INTERVAL_MS = 60000     # Health alle 60s pruefen
HEALTH_SOFT_RECONNECT_MS = 300000    # Nach 5 min Stille: WLAN+MQTT neu verbinden
HEALTH_HARD_RESET_MS = 900000        # Nach 15 min Stille: machine.reset()

# Reset-Cause-Diagnose: boot.py schreibt /_boot_info.txt mit dem letzten
# reset_cause(). Nach dem ersten erfolgreichen MQTT-Connect publishen wir
# das einmal auf tele/solar/BOOT (retained) - so kann der Broker auch nach
# einem 'raetselhaften' Stall belegen, welcher Reset-Typ wirklich gegriffen hat.
_boot_info_published = False

# System-Status für Monitoring
system_status = {
    'uptime': 0,          # Betriebszeit in Sekunden
    'heap_free': 0,       # Freier Heap-Speicher in Bytes
    'wifi_rssi': 0,       # WLAN-Signalstärke in dBm
    'last_error': None,   # Letzter aufgetretener Fehler
    'boot_time': None,    # Boot-Zeitstempel
    'ntp_sync_count': 0   # Anzahl erfolgreicher NTP-Synchronisationen
}

# HTML Template
html_template = """<!DOCTYPE html>
<html><head>
<meta http-equiv='refresh' content='5'>
<meta charset='UTF-8'>
<style>
body {{ background:#fff; font-family:sans-serif; padding:10px; }}
b {{ font-size:16px; }}
small {{ color:#666; }}
.emerg {{ background:#c00; color:#fff; padding:6px; margin-bottom:8px; font-weight:bold; }}
input,button {{ padding:4px; margin:2px; font-size:14px; }}
form {{ margin:8px 0; }}
</style></head><body>
{8}
<b>Solarpanel</b><br>
Aktuell: {0} <small>(roh: {6})</small><br>
Ziel: {1:.1f}°<br>
Motor: {2}<br>
Bereich: {3:.1f}° – {7:.1f}°<br>
Tracking: {9}<br>
<form method='POST'>
<input name='minangle' type='number' step='0.1' value='{4:.1f}'>
<input name='save' type='submit' value='Min setzen'>
<input name='reset' type='submit' value='Reset'>
</form>
<form method='POST'>
<button name='manual' value='down'>⬇️</button>
<button name='manual' value='up'>⬆️</button>
<button name='manual' value='auto'>🔁</button>
</form><small>Zeit: {5}</small>
</body></html>"""

# =============================================================================
# HILFSFUNKTIONEN
# =============================================================================

def calculate_optimal_angle():
    """Optimaler Panel-Neigungswinkel (Grad zur Horizontalen, Sued-Ausrichtung)
    so dass die direkte Sonneneinstrahlung moeglichst senkrecht aufs Panel trifft.

    beta_opt = 90 - Sonnenhoehe(t, lat, lon)
    Sonnenhoehe per Standard-Astronomie (Deklination + Stundenwinkel).
    Frueher hier: base+decl+seasonal - das stand im Sommer falsch herum (steiler
    statt flacher) und lag bei hoher Sonne ~25 Grad daneben.
    """
    try:
        # Standort Muenchen
        lat = 48.1351
        lon = 11.5820

        # ESP-RTC laeuft auf lokaler Wandzeit (MEZ/MESZ, gesetzt in sync_time).
        # Fuer den Stundenwinkel brauchen wir UTC.
        t = time.localtime()
        month = t[1]
        hour = t[3]
        minute = t[4]
        doy = t[7]

        # MESZ etwa April-September, MEZ Nov-Februar. In Maerz/Oktober ist die
        # Heuristik um max 2 Tage daneben - das verschiebt beta_opt um <0.3 Grad.
        is_dst = 4 <= month <= 9 or month in (3, 10)
        tz_offset_h = 2 if is_dst else 1
        utc_h = (hour - tz_offset_h) + minute / 60.0

        # Deklination der Sonne
        decl = 23.45 * math.sin(math.radians(360 / 365 * (doy - 81)))

        # Zeitgleichung (Minuten)
        B = math.radians(360 / 365 * (doy - 81))
        eot = 9.87 * math.sin(2 * B) - 7.53 * math.cos(B) - 1.5 * math.sin(B)

        # Wahre Ortszeit am Laengengrad (Stunden)
        lst = utc_h + lon / 15.0 + eot / 60.0

        # Stundenwinkel (Grad, 0=Mittag, positiv = Nachmittag/West)
        omega = math.radians((lst - 12.0) * 15.0)

        # Sonnenhoehe ueber Horizont
        phi = math.radians(lat)
        delta = math.radians(decl)
        sin_h = math.sin(phi) * math.sin(delta) + math.cos(phi) * math.cos(delta) * math.cos(omega)
        if sin_h > 1.0:
            sin_h = 1.0
        elif sin_h < -1.0:
            sin_h = -1.0
        elevation = math.degrees(math.asin(sin_h))

        optimal = 90.0 - elevation

        print("Astro: doy={} decl={:.1f} lst={:.2f}h elev={:.1f} beta_opt={:.1f}".format(
            doy, decl, lst, elevation, optimal))

        # Auf mechanische Endlagen des Aktuators clampen
        max_a = getattr(env, "MAX_ANGLE", 70.0)
        return max(env.MIN_ANGLE, min(max_a, round(optimal, 1)))
    except Exception as e:
        print("Winkel-Berechnung Fehler:", e)
        return env.MIN_ANGLE

def is_night():
    t = time.localtime()
    return t[3] < sunrise or t[3] >= sunset

def calculate_sunset_local_h():
    """Sonnenuntergang als lokale Wandzeit in Stunden (Float, z.B. 21.5 = 21:30).
    Aus dem Stundenwinkel beim Untergang: cos(omega) = -tan(phi)*tan(delta).
    Selbe Astronomie-Konstanten wie calculate_optimal_angle()."""
    try:
        lat = 48.1351
        lon = 11.5820
        t = time.localtime()
        month = t[1]
        doy = t[7]
        is_dst = 4 <= month <= 9 or month in (3, 10)
        tz_offset_h = 2 if is_dst else 1

        decl = 23.45 * math.sin(math.radians(360 / 365 * (doy - 81)))
        B = math.radians(360 / 365 * (doy - 81))
        eot = 9.87 * math.sin(2 * B) - 7.53 * math.cos(B) - 1.5 * math.sin(B)

        phi = math.radians(lat)
        delta = math.radians(decl)
        cos_omega = -math.tan(phi) * math.tan(delta)
        if cos_omega < -1.0 or cos_omega > 1.0:
            # Polartag/Polarnacht - in Muenchen unerreichbar. Fallback.
            return 18.0
        omega_sunset_rad = math.acos(cos_omega)
        half_day_h = math.degrees(omega_sunset_rad) / 15.0
        lst_sunset = 12.0 + half_day_h
        local_h = lst_sunset - lon / 15.0 - eot / 60.0 + tz_offset_h
        if local_h < 0:
            local_h += 24
        if local_h >= 24:
            local_h -= 24
        return local_h
    except Exception as e:
        print("Sunset-Berechnung Fehler:", e)
        return 18.0

def _current_local_h():
    t = time.localtime()
    return t[3] + t[4] / 60.0 + t[5] / 3600.0

def _fmt_hours_hhmm(h):
    """Float-Stunde -> 'HH:MM' (z.B. 20.5 -> '20:30')."""
    try:
        if h < 0:
            h += 24
        if h >= 24:
            h -= 24
        hh = int(h)
        mm = int(round((h - hh) * 60))
        if mm == 60:
            hh = (hh + 1) % 24
            mm = 0
        return "{:02d}:{:02d}".format(hh, mm)
    except Exception:
        return "--:--"

def tracking_window():
    """Liefert (start_h, end_h) des heutigen Aktiv-Fensters in lokalen Stunden."""
    start_h = TRACK_START_H
    end_h = calculate_sunset_local_h() - TRACK_END_BEFORE_SUNSET_H
    return start_h, end_h

def is_tracking_active():
    """True wenn das Panel aktuell aktiv nachgefuehrt werden soll.
    Ausserhalb -> target wird auf MIN_ANGLE gezogen (Panel flach)."""
    start_h, end_h = tracking_window()
    now_h = _current_local_h()
    return start_h <= now_h < end_h

def get_formatted_time():
    """Formatierte deutsche Zeit zurückgeben"""
    try:
        t = time.localtime()
        return "{:02d}.{:02d}.{} {:02d}:{:02d}:{:02d}".format(
            t[2], t[1], t[0], t[3], t[4], t[5]
        )
    except:
        return "Zeitfehler"

def sync_time():
    """NTP-Zeitaktualisierung mit präziser deutscher Zeitzone"""
    global system_status
    try:
        import ntptime
        print("Synchronisiere Zeit via NTP...")
        
        # Deutsche NTP-Server verwenden
        ntp_servers = [
            "pool.ntp.org",
            "de.pool.ntp.org", 
            "time.google.com",
            "ptbtime1.ptb.de"
        ]
        
        success = False
        for server in ntp_servers:
            try:
                ntptime.host = server
                ntptime.settime()
                success = True
                system_status['ntp_sync_count'] += 1
                print(f"Zeit synchronisiert mit {server}")
                break
            except Exception as e:
                print(f"NTP-Server {server} nicht erreichbar: {e}")
                continue
        
        if success:
            # Präzise deutsche Sommerzeit-Berechnung
            utc_time = time.localtime()
            year = utc_time[0]
            month = utc_time[1]
            day = utc_time[2]
            hour = utc_time[3]
            
            # Sommerzeit in Deutschland: Letzter Sonntag im März bis letzter Sonntag im Oktober
            # Berechnung der Übergangstage
            def last_sunday_of_month(year, month):
                # Letzter Tag des Monats
                if month == 12:
                    next_month_first = time.mktime((year + 1, 1, 1, 0, 0, 0, 0, 0, 0))
                else:
                    next_month_first = time.mktime((year, month + 1, 1, 0, 0, 0, 0, 0, 0))
                last_day = time.localtime(next_month_first - 86400)[2]
                
                # Finde letzten Sonntag
                for d in range(last_day, last_day - 7, -1):
                    weekday = time.localtime(time.mktime((year, month, d, 0, 0, 0, 0, 0, 0)))[6]
                    if weekday == 6:  # Sonntag
                        return d
                return last_day  # Fallback
            
            # Sommerzeit-Grenzen berechnen
            dst_start_day = last_sunday_of_month(year, 3)   # Letzter Sonntag im März
            dst_end_day = last_sunday_of_month(year, 10)    # Letzter Sonntag im Oktober
            
            # Prüfung ob aktuell Sommerzeit
            is_dst = False
            if month < 3 or month > 10:
                is_dst = False  # Januar, Februar, November, Dezember
            elif month > 3 and month < 10:
                is_dst = True   # April bis September
            elif month == 3:
                # März: Nach dem letzten Sonntag um 2:00 MEZ (1:00 UTC)
                if day > dst_start_day:
                    is_dst = True
                elif day == dst_start_day and hour >= 1:  # 2:00 MEZ = 1:00 UTC
                    is_dst = True
            elif month == 10:
                # Oktober: Vor dem letzten Sonntag um 3:00 MESZ (1:00 UTC)
                if day < dst_end_day:
                    is_dst = True
                elif day == dst_end_day and hour < 1:  # 3:00 MESZ = 1:00 UTC
                    is_dst = True
            
            # Zeitzone anwenden
            tz_offset = 7200 if is_dst else 3600  # MESZ: UTC+2, MEZ: UTC+1
            local_timestamp = time.mktime(utc_time) + tz_offset
            local_time = time.localtime(local_timestamp)
            
            # System-Zeit auf lokale Zeit setzen (MicroPython Workaround)
            try:
                # Zeitverschiebung für interne Uhr
                machine.RTC().datetime((
                    local_time[0], local_time[1], local_time[2], 
                    local_time[6], local_time[3], local_time[4], 
                    local_time[5], 0
                ))
            except:
                pass  # Fallback falls RTC nicht verfügbar
            
            # Boot-Zeit setzen wenn noch nicht gesetzt
            if system_status['boot_time'] is None:
                system_status['boot_time'] = get_formatted_time()
            
            print(f"Aktuelle Zeit: {local_time[2]:02d}.{local_time[1]:02d}.{local_time[0]} {local_time[3]:02d}:{local_time[4]:02d}:{local_time[5]:02d}")
            print(f"Zeitzone: {'MESZ (UTC+2)' if is_dst else 'MEZ (UTC+1)'}")
            
            # Debug-Informationen
            print(f"DST-Start: {dst_start_day}.03.{year}, DST-Ende: {dst_end_day}.10.{year}")
            
            return True
        else:
            print("Alle NTP-Server nicht erreichbar - verwende Systemzeit")
            system_status['last_error'] = "NTP sync failed"
            return False
            
    except ImportError:
        print("ntptime-Modul nicht verfügbar")
        system_status['last_error'] = "ntptime module missing"
        return False
    except Exception as e:
        print(f"Zeit-Synchronisation fehlgeschlagen: {e}")
        system_status['last_error'] = f"NTP sync error: {str(e)}"
        return False

# =============================================================================
# MQTT FUNKTIONEN
# =============================================================================

def mqtt_on_message(topic, msg):
    """Callback fuer eingehende MQTT-Befehle (cmnd/solar/...)."""
    global emergency_mode, target, manual_override, angle
    try:
        t = topic.decode() if isinstance(topic, (bytes, bytearray)) else topic
        m = (msg.decode() if isinstance(msg, (bytes, bytearray)) else msg).strip().lower()
        print("MQTT cmd:", t, "=", m)
        if t.endswith("/EMERGENCY"):
            new = m in ("on", "1", "true", "yes")
            if new != emergency_mode:
                emergency_mode = new
                manual_override = False
                if new:
                    target = env.MIN_ANGLE
                    print("EMERGENCY ON - target=MIN_ANGLE ({})".format(env.MIN_ANGLE))
                    mqtt_publish_debug("Emergency ON")
                else:
                    angle = calculate_optimal_angle()
                    target = angle if is_tracking_active() else env.MIN_ANGLE
                    print("EMERGENCY OFF - target={:.1f}".format(target))
                    mqtt_publish_debug("Emergency OFF")
                # State sofort zurueckspiegeln
                try:
                    mqtt.publish(f"{env.MQTT_TOPIC_SENSOR}/Emergency", "true" if new else "false")
                except:
                    pass
    except Exception as e:
        print("MQTT-Callback Fehler:", e)


def _mqtt_arm_timeout():
    """Setzt den Socket-Timeout auf dem aktiven MQTT-Socket (neu).
    MUSS vor jedem blockierenden publish()/ping()/disconnect() aufgerufen
    werden: umqtt.simple.check_msg() setzt den Socket per setblocking(True)
    jedes Mal wieder auf 'blockierend OHNE Timeout' zurueck. Ohne dieses
    Neu-Setzen kann ein einzelnes publish() den Loop fuer immer einfrieren
    (siehe Kommentar bei MQTT_SOCKET_TIMEOUT)."""
    try:
        if mqtt is not None and getattr(mqtt, 'sock', None) is not None:
            mqtt.sock.settimeout(MQTT_SOCKET_TIMEOUT)
    except Exception:
        pass


def mqtt_connect():
    """MQTT-Verbindung aufbauen und auf Commands subscriben."""
    global mqtt, mqtt_connected, system_status
    try:
        if mqtt:
            # Alter Socket koennte haengen -> Timeout setzen, damit das
            # disconnect() (sendet ein DISCONNECT-Paket) nicht blockiert.
            _mqtt_arm_timeout()
            try:
                mqtt.disconnect()
            except:
                pass

        mqtt = MQTTClient(
            env.MQTT_CLIENT_ID,
            env.MQTT_SERVER,
            port=env.MQTT_PORT,
            user=env.MQTT_USER,
            password=env.MQTT_PASSWORD,
            keepalive=60
        )
        mqtt.set_callback(mqtt_on_message)
        mqtt.connect()
        mqtt_connected = True
        # Frischer Socket -> sofort Timeout setzen, schuetzt alle folgenden
        # publish()/ping()-Aufrufe vor dem Endlos-Block.
        _mqtt_arm_timeout()
        print(f"MQTT verbunden mit {env.MQTT_SERVER}:{env.MQTT_PORT}")

        # Subscribe auf Command-Topics (retain-Messages kommen sofort)
        cmd_base = getattr(env, 'MQTT_TOPIC_CMD', 'cmnd/solar')
        cmd_topic = cmd_base + "/EMERGENCY"
        try:
            mqtt.subscribe(cmd_topic)
            print("Subscribed:", cmd_topic)
        except Exception as e:
            print("Subscribe-Fehler:", e)

        # Status-Nachricht senden
        mqtt_publish_status("online", retain=True)

        # Boot-Diagnose einmalig publishen (retained, ueberlebt also Broker-Restart)
        _publish_boot_info_once()
        return True

    except Exception as e:
        mqtt_connected = False
        system_status['last_error'] = f"MQTT connect error: {str(e)}"
        print(f"MQTT-Verbindung fehlgeschlagen: {e}")
        return False
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

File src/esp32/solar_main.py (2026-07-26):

# Olimex ESP32-EVB-EA Solar Panel Controller
# MicroPython 1.27+ ESP32_GENERIC
#
# Features:
# - Astronomische Sonnenwinkel-Berechnung (Azimut-aware Optimum, S-Tilt)
# - MPU-6050 Regelung mit asymmetrischer Hysterese
# - MQTT-Telemetrie + Commands (Manual, MinAngle, Emergency, SetAngle, Recalc)
# - WebGUI (Dashboard + Manual-Buttons + Kalibrierung), nonblocking auf :80
# - WebREPL fuer Fernwartung
# - 3-Layer-Watchdog + UDP-Keepalive + WLAN-Auto-Reconnect
#
# Init-Reihenfolge (MPU-optional): WLAN -> MQTT -> MPU (optional) -> HTTP -> WDT
# Ohne MPU laeuft WebGUI + MQTT + Diagnose weiter, Motor bleibt aus (Sicherheit).

import machine
import time
import network
import gc
import sys
if sys.platform == "esp8266":
    import esp
else:
    class _EspCompat:
        SLEEP_NONE = 0
        @staticmethod
        def sleep_type(*_a, **_kw):
            return 0
    esp = _EspCompat()
import socket
import errno
import math
import uselect
import ujson
import uos
from umqtt.simple import MQTTClient
from mpu6050 import MPU6050

import env
print("env.py geladen")

# =============================================================================
# GLOBALE VARIABLEN
# =============================================================================

sensor = None
rel1 = None
rel2 = None
mqtt = None
wdt = None
http_sock = None
reboot_pending_at_ms = 0

current_angle = None
current_angle_raw = None
angle = 35.0
target = 30.0
tolerance = 2.0
motion_dir = 0
manual_override = False
emergency_mode = False

sunset = 21
sunrise = 8
tz_offset_hours = 2

mqtt_connected = False
last_mqtt_publish = 0
mqtt_publish_interval = 30000
last_mqtt_connect_attempt = 0
_boot_info_published = False
mqtt_reconnect_interval = 60000
last_mqtt_ping = 0
mqtt_ping_interval = 30000

last_successful_publish_ticks = 0
PUBLISH_STALE_MS = 300000

last_ping_sent_token = 0
last_ping_sent_ticks = 0
last_echo_seen_ticks = 0
ECHO_INTERVAL_MS = 60000
ECHO_TIMEOUT_MS = 120000

boot_ticks = 0
SCHEDULED_REBOOT_MS = 21600000

udp_keepalive = None
udp_keepalive_gw = None

system_status = {
    'uptime': 0,
    'heap_free': 0,
    'wifi_rssi': 0,
    'last_error': None,
    'boot_time': None,
    'ntp_sync_count': 0
}

# =============================================================================
# ASTRO
# =============================================================================

def _solar_elevation_at(offset_hours=0.0):
    t = time.localtime()
    doy = t[7]
    local_hour = t[3] + t[4]/60.0 + t[5]/3600.0 + offset_hours
    utc_hour = local_hour - tz_offset_hours
    lat = math.radians(getattr(env, "LATITUDE", 48.066))
    lon = getattr(env, "LONGITUDE", 11.667)
    B = math.radians(360.0/365.0 * (doy - 81))
    decl = math.radians(23.45) * math.sin(B)
    eot_min = 9.87*math.sin(2*B) - 7.53*math.cos(B) - 1.5*math.sin(B)
    solar_time = utc_hour + lon/15.0 + eot_min/60.0
    H = math.radians((solar_time - 12.0) * 15.0)
    sin_elev = math.sin(decl)*math.sin(lat) + math.cos(decl)*math.cos(lat)*math.cos(H)
    sin_elev = max(-1.0, min(1.0, sin_elev))
    return math.degrees(math.asin(sin_elev))

def _solar_position():
    t = time.localtime()
    doy = t[7]
    local_hour = t[3] + t[4]/60.0 + t[5]/3600.0
    utc_hour = local_hour - tz_offset_hours
    lat = math.radians(getattr(env, "LATITUDE", 48.066))
    lon = getattr(env, "LONGITUDE", 11.667)
    B = math.radians(360.0/365.0 * (doy - 81))
    decl = math.radians(23.45) * math.sin(B)
    eot_min = 9.87*math.sin(2*B) - 7.53*math.cos(B) - 1.5*math.sin(B)
    solar_time = utc_hour + lon/15.0 + eot_min/60.0
    H = math.radians((solar_time - 12.0) * 15.0)
    sin_elev = math.sin(decl)*math.sin(lat) + math.cos(decl)*math.cos(lat)*math.cos(H)
    sin_elev = max(-1.0, min(1.0, sin_elev))
    elev = math.asin(sin_elev)
    den = math.cos(elev)*math.cos(lat)
    if abs(den) < 1e-9:
        azi = math.pi
    else:
        cos_azi = (math.sin(decl) - math.sin(elev)*math.sin(lat)) / den
        cos_azi = max(-1.0, min(1.0, cos_azi))
        azi = math.acos(cos_azi)
    if H > 0:
        azi = 2*math.pi - azi
    return math.degrees(elev), math.degrees(azi)


def calculate_optimal_angle():
    try:
        elev_deg, az_deg = _solar_position()
        if elev_deg <= 0:
            return env.MIN_ANGLE
        elev_r = math.radians(elev_deg)
        az_r = math.radians(az_deg)
        tilt_r = math.atan2(-math.cos(az_r) * math.cos(elev_r), math.sin(elev_r))
        tilt_deg = math.degrees(tilt_r)
        if tilt_deg < 0:
            tilt_deg = 0.0
        min_a = env.MIN_ANGLE
        max_a = getattr(env, "MAX_ANGLE", 70.0)
        result = max(min_a, min(max_a, tilt_deg))
        print("Sonne: elev={:.1f} az={:.1f} -> opt={:.1f} -> Ziel={:.1f}".format(
            elev_deg, az_deg, tilt_deg, result))
        return round(result, 1)
    except Exception as e:
        print("Winkel-Berechnung Fehler:", e)
        return env.MIN_ANGLE

def is_night():
    t = time.localtime()
    morning_start = int(getattr(env, "MORNING_START_HOUR", 8))
    try:
        if _solar_elevation_at(0.0) <= 0.0:
            return True
        margin = float(getattr(env, "SUNSET_MARGIN_HOURS", 1.0))
        if _solar_elevation_at(margin) <= 0.0:
            return True
        return False
    except Exception:
        return t[3] < morning_start or t[3] >= sunset

def get_formatted_time():
    try:
        t = time.localtime()
        return "{:02d}.{:02d}.{} {:02d}:{:02d}:{:02d}".format(
            t[2], t[1], t[0], t[3], t[4], t[5]
        )
    except:
        return "Zeitfehler"
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

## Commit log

2026-05-16 Initial release: FollowMySun – ESP8266 PV-Tracker mit MQTT-Sturmschutz
    Komplette Dokumentation, Source-Code und Jekyll-Pages-Setup.
    - src/: MicroPython-Code fuer ESP12F-Relay-X4 (boot, main loader,
    solar_main mit Astro-Berechnung, MPU-6050-Treiber, env-Template)
    - docs/: hardware, installation, mqtt, calibration, software,
    nodered-stormwatch - mit echten Fotos vom Aufbau
    - index.md + _config.yml fuer GitHub Pages (minimal theme)
    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
2026-05-27 Sun-Azimuth-Tracking, Tagesfenster, BOOT-Diagnose und Live-Kalibrierung
    - calculate_optimal_angle() nutzt jetzt projizierte Single-Axis-Formel
    (atan(tan(zenith)*cos(azi-panel_azi))) statt nur Elevation, sonst zielt
    der Tracker morgens/abends auf falsche Winkel.
    - _solar_position() / _solar_elevation_at() implementieren NOAA-Sonnenstand
    mit Equation of Time. DST wird in sync_time() ausgewertet (tz_offset_hours).
    - is_night() haelt Panel vor MORNING_START_HOUR (Default 08:00) flach und
    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
2026-05-27 calculate_optimal_angle: Elevation-Tracking statt Azimut-Projektion
    Die azimut-projizierte Formel atan(tan(zenith)*cos(azi-180)) ist
    mathematisch energieoptimal, liefert aber bei Sonne im Osten/Westen
    flach (MIN_ANGLE), weil ein nur Nord-Sued-kippendes Panel die seitliche
    Sonne nicht "anschauen" kann. Visuell wirkt das wie "Panel ignoriert
    aufgehende Sonne".
    Wechsel auf klassisches Elevation-Tracking tilt = 90 - elev:
    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
2026-05-31 loop: WLAN-Reconnect alle 30s nachruesten
    Wenn die AP-Assoziation kippt (schwaches RSSI, AP-Reboot, Deauth),
    hat der ESP bisher stundenlang gelaufen und WDT gefuettert, aber
    mit totem Netzwerk-Stack: kein MQTT, kein Webserver. Erforderte
    jedes Mal manuellen Strom-Reset.
    Loop prueft jetzt alle 30s isconnected() und ruft bei Bedarf
    disconnect() + active(True) + connect() auf. mqtt_connected wird
    zurueckgesetzt, damit mqtt_check_connection() im naechsten Zyklus
    einen frischen Reconnect versucht statt in tote Sockets zu pingen.
    esp.sleep_type(SLEEP_NONE) wird nach Reconnect neu gesetzt.
    [solar_main.py]
2026-06-01 loop: Stale-Publish-Watchdog -> machine.reset() bei MQTT-Stillstand
    Symptom: Loop laeuft brav weiter (Hardware-WDT wird gefuettert),
    aber MQTT/WLAN sind tot - z.B. wenn Heap so weit faellt, dass
    ujson.dumps oder _wlan.connect() im OOM landen. Ohne diesen
    Sicherheitsanker bleibt der ESP bis zum manuellen Reset stehen.
    Fix: in mqtt_publish_sensor_data() wird bei jedem erfolgreichen
    Publish last_successful_publish_ticks gestempelt. Wenn 5 min lang
    nichts mehr durchgeht, Relays aus, _reset_info.txt schreiben,
    machine.reset(). Grace-Window ab init().
    [solar_main.py]
2026-06-01 solar_main: Defense-in-Depth gegen Haenger (L1+L2+L3)
    Beobachtung: Nach dem Stale-Publish-Watchdog (Commit 41f9929) gab es
    weiterhin Haenger, die einen Hardware-Reset erforderten. Root-Cause-Analyse
    ergab: umqtt.simple publish() ist QoS=0 fire-and-forget - returnt erfolgreich
    auch wenn die Pakete bei WLAN-Modem-Stuck oder TCP CLOSE_WAIT den Broker nie
    erreichen. Damit war der bisherige Watchdog blind, weil last_successful_
    publish_ticks trotzdem gestempelt wurde. Zusaetzlich Heap-Druck: 11 separate
    mqtt.publish() Calls pro 30s-Cycle plus ein konsolidiertes JSON = 12
    Allokationen.
    Drei Schichten Defense in Depth:
    L1 - Heap-Konsolidierung in mqtt_publish_sensor_data():
    - 11 single-topic Pu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
    [solar_main.py]
2026-06-05 solar_main: Webserver raus + Azimut-aware Sun-Tracking
    Ursache fuer wiederkehrende WLAN-Drops: Webserver auf ESP8266 war Heap-
    Killer. html_template.format() + HTTP-Header + encode() = ~1.5 KB
    Allokation je Request. Auto-Refresh im HTML (5s) + Iframe im HA-Subview
    = permanente Request-Last bei nur ~6 KB freiem Heap = Fragmentation +
    TCP-Stack-Stalls. Bestaetigt vor Umbau: Heap fiel kontinuierlich von
    ~6.5 KB auf <5.5 KB, dann WLAN-Stack stuck, dann Hardware-Reset noetig.
    Loesung: handle_web_request + start_web + html_template + srv-Socket
    komplett raus. Steuerung jetzt ueber MQTT:
    cmnd/solar/MANUAL payload: up|down|auto
    cmnd/solar/MIN_ANGLE payload: 0..70 (float)
    cmnd/solar/RECALC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
    [solar_main.py]
2026-06-06 mqtt: echtes LWT auf tele/solar/LWT statt Status-Topic
    Bisher: stat/esp_solar/STATUS mit Payload "online"/"offline" als Heartbeat.
    Problem: kein echtes MQTT-Last-Will — bei haengendem ESP oder gerissener
    WLAN-Verbindung kommt das "offline"-Payload nie an, der HA-Sensor blieb
    ewig auf "on". Drops waren in der Subview unsichtbar.
    set_last_will(b"tele/solar/LWT", b"Offline", retain=True) vor connect();
    direkt nach connect publish "Online" retain. Broker uebernimmt das
    "Offline"-Publish automatisch wenn TCP/keepalive bricht.
    [solar_main.py]
2026-07-19 docs: Migration-Guide ESP12F-Relay-X4 -> Olimex ESP32-EVB-EA
    Neuer Doku-Pfad docs/hardware-migration-esp32-evb.md mit vier
    Mermaid-Diagrammen (IST, SOLL-Power, SOLL-Signale, Klemmen-Detail).
    Kernpunkt: Olimex ist strikt 5 V (TPS62A02, abs. Max 5.5 V), 12 V
    darf nicht wie beim alten Board direkt aufs Board. Loesung: WAGO 221
    T-Verzweigung + Mini-360 Buck auf DC-Jack 5.5x2.1 mm fuer die Logik,
    paralleler 12 V-Zweig direkt an REL1-COM/REL2-COM fuer die Aktuator-Last.
    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
2026-07-20 Morgen-Nachfuehrung auf echte Sonnenstandsberechnung umgestellt, ESP32-Bootstrap-Erkenntnisse dokumentiert
    is_night() nutzte morgens einen festen 08:00-Cutoff statt astronomischer
    Berechnung (inkonsistent zur bereits echten Abend-Logik) - live am
    Produktivgeraet (ESP-12F, 10.10.12.92) gefixt und verifiziert.
    Zusaetzlich Lessons Learned vom ESP32-EVB-EA-Werkbank-Bootstrap
    dokumentiert (Serial-Port-Identifikation, MPU6050-Fail-Safe,
    Parallelbetrieb-Falle bei gleicher MQTT-Client-ID).
    [solar_main.py]
2026-07-23 docs: Wiring-Uebersicht ESP32-EVB - alle vier Schaltbilder auf einer Seite
    Neue Seite docs/wiring-esp32-evb.md buendelt die vier Migrations-SVGs
    (IST ESP12F, SOLL Power-Pfad, SOLL Signal-/Lastpfad, Klemmen-Detail) als
    Werkbank-Referenz zum Ausdrucken, inkl. Farbcode-Legende, UEXT-Pinout,
    Klemmentabelle und Sicherheits-Remindern.
    Diagramme sind als <img> eingebunden statt inline, weil alle vier SVGs
    id="my-svg" mit eigenem Scoped-CSS tragen - inline wuerden sich die
    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
2026-07-24 esp32: WebGUI + REST-API + robuster init (MPU-optional)
    - src/esp32/ mit portierter Firmware (boot.py/main.py/mpu6050.py/solar_main.py/
    env.example.py/webrepl_cli.py) inkl. eingebautem HTTP-Server auf :80
    - solar_main.py: init() startet WLAN + MQTT + WebGUI zuerst, MPU-6050 wird
    optional geladen (sensor=None sperrt Motorbewegung, aber Remote-Diagnose
    laeuft weiter) - Feld-Deploy ohne UEXT-Sensor auf der Werkbank testbar
    - REST-Endpoints /api/state, /api/manual, /api/emergency, /api/recalc,
    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
2026-07-26 esp32: /api/reboot Endpoint fuer Fern-Reboot ohne USB
    - POST /api/reboot triggert machine.reset() ~1.5s spaeter
    - global reboot_pending_at_ms + main-loop Poll
    (Timer(-1) mit callback wird ohne Referenz GC'ed - Bug vermieden)
    - WebGUI: neuer Reboot-Button (mit confirm-Dialog)
    - Loest USB-Abhaengigkeit fuer Boards im Feld/Schuppen
    [solar_main.py]
2026-07-26 docs: HA Storm Guard - lokale Wind-Automatik ueber HTTP-Endpoint
    Neue Doku fuer den zweiten Sturmschutz-Layer (lokale Wetterstation) neben
    dem existierenden NodeRED-DWD-Flow. Vollstaendiges HA-Package mit
    Input-Helpers, Template-Sensor, Automations und REST-Commands enthalten.
    Warum HTTP statt cmnd/solar/EMERGENCY-MQTT: MQTT-Sub am Olimex faellt
    gelegentlich nach Reconnects aus - HTTP an den bestehenden Reverse-Proxy
    (10.10.0.100:8055) ist zuverlaessiger und braucht keine Board-Firmware-
    Aenderungen.
2026-07-26 docs(storm-guard): Screenshots Olimex WebGUI + HA Helpers + Automations
    Drei Live-Screenshots zeigen den End-to-End-Status:
    - Olimex WebGUI (Panel-Zustand, Emergency-Buttons, Reboot)
    - HA Helpers (die 6 pv_storm_* Input-Nummern/-Boolans)
    - HA Automations-Liste (3 Storm-Guard Automations, alle aktiv)
    Keine sensiblen Daten in den Bildern (nur interne IPs die bereits in
    anderen Dokus vorkommen).
2026-07-26 docs(storm-guard): Sidebar aus HA-Screenshots croppen
    Entfernt aus 02-ha-helpers.jpg und 03-ha-automations.jpg die HA-Sidebar
    (zeigt sonst Benutzernamen und alle Menüpunkte). Nur noch der relevante
    Content-Bereich rechts vom Sidebar.
2026-08-04 Update tracker sources to current local final variant
2026-09-16 Add Olimex ESP32-EVB enclosure documentation images
2026-09-16 Add parametric Olimex ESP32-EVB enclosure v0.3
    [olimex_esp32_evb_ea_roof_housing_v0.3.scad]
2026-09-16 Document Olimex enclosure source package
2026-09-16 Add reproducible OpenSCAD enclosure build script
2026-09-16 Add Rev-L source coordinates for enclosure
2026-09-16 Add mesh QA results for enclosure v0.3
2026-09-16 Add Olimex ESP32-EVB enclosure documentation page
2026-09-16 Link Olimex enclosure v0.3 from project README
2026-09-16 Add enclosure v0.3 to GitHub Pages index
